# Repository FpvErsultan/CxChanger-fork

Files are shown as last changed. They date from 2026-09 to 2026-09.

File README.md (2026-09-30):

## 🧑‍🔧 玩家社区 / Community

**上传模型和图片、分享作品、参与投票，无需会 Git：** [直接进入玩家作品社区（上传模型） →](https://ers-ye.github.io/cxchanger/community/) · [在 GitHub 讨论区交流](https://github.com/ers-ye/cxchanger/discussions)

---

## 最新项目 / Project Update

- [后置换热端项目（中文）](./后置换热端/README.md) | [English](./后置换热端/README_EN.md)
- [6.11 CNC 文件包](./6.11%20cnc.zip)

# [CxChanger]

[CxChanger]是一种FDM3D打印多材料/多色解决方案。通过在打印打印过程中切换预热好的装载不同耗材的热端实现快速多材料打印。其目标是实现尽可能低成本且简单稳定的多材料打印，为了实现较高的适配性，热端切换只需要打印头XY轴运动就可实现，且切换结构与热端无关，可以通过修改热端固定件等实现其他热端的兼容。

English language readme is available [here](./EN-translation/README-EN.md)

打印头

QQ20260404-193802

---

## 核心特性
- **自动预热**：开启orcaslicer中的Ooze预防功能，会根据自己设定的预热时间提前在切换材料前插入预热命令，切换时释放旧热端并切换到待机温度然后抓取已经预热好的热端，若下一次切换的时间短于加热时间则保持温度不降温。
- **欠驱动切换机构**：采用欠驱动设计不需要额外增加主动元件，利用打印头自身的XY轴运动与停靠坞机械交互来实现热端切换和耗材丝夹紧松开。
- **磁吸麦克斯韦定位耦合机构**：热端模块锁定采用N52磁铁磁吸配合[麦克斯韦耦合](https://en.wikipedia.org/wiki/Kinematic_coupling)定位机构，打印头端有定位销组成的三个槽口，热端模块端有圆头销头部组成的球头。磁吸配合时实现对热端模块空间六自由度的限位，不存在过定位所以即使有加工装配误差以及磨损变形热端模块都能自适应消隙精确定位。
- **自动喷嘴偏移量校准**:采用校准器校准每个头XYZ轴相对T0的偏移量，可以使用如[小球微动接触式喷嘴偏移量校准](https://github.com/Noisyfox/FoxChanger/tree/main/NozzleProbe)或者[无接触涡流喷嘴偏移量校准](https://oshwhub.com/cxg01/project_lbabffjk)，接触式需要清理干净喷嘴才能获得正确喷嘴偏移量，无接触可以不清理喷嘴。不需要每次打印前都校准，通常在刚装配好或者出现撞头等情况需要校准。

## 硬件与软件需求

### 硬件
* **打印机** 原理上支持打印头具有XY移动能力的机型（如voron2.4、voron三叉戟、大鱼TT等），本开源只提供打印头和基础停靠坞设计需要根据自己机型固定装载停靠坞的铝型材和其他兼容修改。
* **主板** 由于采用有线加热，每个热端模块具有一个加热片和热敏，可利用主板空余接口来扩展少量热端模块，若需要扩展更多热端模块需要制作[扩展板]( https://oshwhub.com/rayzark/project_qxihkkhj)来增加主板的加热棒接口和热敏接口。

### 软件
* **固件** 整体热端切换通过klipper宏命令实现，若需使用喷嘴偏移量校准则需要下载[toolchange](https://github.com/viesturz/klipper-toolchanger)插件，配合自动校准宏来实现。
* **切片软件**：采用Orcaslicer，其他切片软件可自行探索。

## 组成概览

### 组成部分
- 打印头：有除了热端以外的其他部分
- 热端模块：包含热端，接有铁氟龙管和加热片和热敏的线
- 停靠坞：用于存放停靠的热端，可以堵住停靠热端的嘴防止漏料，以及有散热风扇给停靠的热端进行散热（无封箱的采用侧面离心风扇对所有热端进行散热、有封箱的采用每个停靠坞一个轴流风扇）。

### 零件
#### 打印版
- 1.5×5（直径*长）圆柱销：用于构成麦克斯韦耦合定位的槽（×6）
- 3×6（直径*长）圆头销：用于构成麦克斯韦耦合定位的球（一个热端3个）
- 5×20（直径*长）内螺纹圆头销：装配于停靠坞上用于撑开挤出机摆臂（一个停靠坞1个）
- 6×4（直径*厚）N52磁铁：用于吸附热端模块到打印头上和停靠坞上（一个热端3个，一个停靠坞1个，打印头3个）
- M3×6沉头螺丝
- M3×25螺丝
- M3×8螺丝
- M3×10螺丝
- M3×12螺丝
- M3×14螺丝
- M3×20螺丝
- M2.5×16螺丝
- M2×8螺丝
- M3×4×4热熔螺母
- HGX挤出机齿轮组
- 4020蜗轮风扇
- 2510轴流风扇
- 欧姆龙微动开关
- 10×2（宽×厚）自粘耐热硅胶条
#### CNC版
见bom表

## 安装与配置指南

### printer.cfg
   Printer.cfg主体可以沿用自己以前的，参考我的printer.cfg里的格式和下面的提示修改，也可以直接用我的然后改成自己主板的引脚。
   1. 引用 toolchange.cfg 和 calibration.cfg。
   2. 仿照extruder1格式定义增加的热端，加热棒热敏引脚按自己主板接线来，共用E0的挤出机，其他的为虚拟挤出机。
   3. probe采用固定微动，开始打印时热端全部停放于停靠坞中用耐高温硅胶垫堵嘴，加热到目标温度才拿出来解决初始漏料问题，不需要擦嘴，调平时未抓取热端此时微动为打印头最低点。还未支持其他调平方式，建议直接参考我的probe相关配置包括网床和调平的配置（主要是增加了调平前释放抓取的热端）。
   4. 添加停靠坞散热风扇配置，停靠坞散热风扇和喉管冷却风扇关联的挤出机里添加所有挤出机。
   5. 修改打印开始gcode，实现打印前自动给要使用的热端进行挤出划线。
   6. 修改打印结束gcode，添加UNTOOL命令保证打印完自动卸载热端，让下次打印时不用自己手动取下热端。增加关闭所有热端加热命令。
### toolchange.cfg
   1. 添加toolchange.cfg。添加成功后仪表盘界面会出现T0、T1、T2以及、UNTOOL命令，（没调坐标先别点、会直接撞）点击T0是抓去T0，抓取T0后再点击T1坐标会自动卸载T0然后抓取T1，点击UNTOOL是卸载当前热端。
   2. 固定停靠坞以及调整停靠坞坐标：手动把热端装到打印头上，把打印头拖动到X轴最右边，再往前拖动，然后把第一个停靠坞固定在能刚好让热端锁定螺丝穿过停靠坞大孔的位置（这个位置即为第一个停靠坞的坐标），然后取下热端，点击全部归位，再把热端装到打印头上，慢慢移动打印头到刚才找到的停靠坞位置让锁定螺丝穿过停靠坞大孔，记下此时的坐标将其填入toolchange里T0的停靠坞位置，一个停靠坞占30mm宽度，其他停靠坞坐标用等差数列得到，如有误差可自己微调每一个停靠坞的坐标。 
   

   3. 正确设置坐标后，注释正常速度，解除测试速度注释，用慢速进行切换测试，（方便看到没对齐直接点急停）。
   4. 测试速度切换正常后，注释测试速度，解除正常速度注释（可以根据自己机器情况自己测试出更为合适的速度）。
### calibration.cfg
   1. 下载[toolchange](https://github.com/viesturz/klipper-toolchanger)插件
   1. 添加calibration.cfg
   2. 归位xyz，调平完成后，固定好校准器，点击T0抓去第一个热端，移动至喷嘴尖端刚好位于校准器中心正上方距离1mm左右，记下这个时候的坐标，填入calibration.cfg里校准器坐标处，然后还需要在里面自己定义一个停靠坞范围外的安全位置，防止校准的时候撞到停靠坞里的其他热端。
   3. 坐标设置好后输入 CALIBRATE_TOOL TOOL=_ 可以校准指定热端（需要先校准T0），输入 CALIBRATE_ALL_TOOLS 可以校准全部（需要设定好有哪些热端），校准完成会自动存储偏移量。
### orcaslicer
   1. 修改打印机gcode里起始和耗材丝更换gcode、设置更多挤出机(根据自己热端数填写)、设置各挤出机切换耗材时回抽量（我设置的长度2mm）。
- 打印起始Gcode(根据自己的热端数修改)：
```Gcode
PRINT_START BED=[first_layer_bed_temperature] INITIAL_TOOL=[initial_tool] T0_TEMP={nozzle_temperature_initial_layer[0]} T0_USED={is_extruder_used[0]} T1_TEMP={nozzle_temperature_initial_layer[1]} T1_USED={is_extruder_used[1]} T2_TEMP={nozzle_temperature_initial_layer[2]} T2_USED={is_extruder_used[2]} T3_TEMP={nozzle_temperature_initial_layer[3]} T3_USED={is_extruder_used[3]} T4_TEMP={nozzle_temperature_initial_layer[4]} T4_USED={is_extruder_used[4]}
```
- 耗材更换Gcode：
```Gcode
M104 S{nozzle_temperature[next_extruder]} T{next_extruder}
T{next_extruder}
```
   2. 工艺栏里开启擦拭塔（如果料和参数调得好，且模型不涉及快速微小挤出，可以把模型拖到停靠坞旁边关掉擦料塔尝试无擦料塔打印）和Ooze自动预热（我设置的软化温度负180，预热时间35s，根据自己热端加热速度修改）。

## 注意事项
- 打印件采用abs打印，4层墙，60%填充。
- 挤出机弹簧需要拧得比常规挤出机更紧（因为为了压缩空间，力臂长度有限相同预紧力下挤出机夹紧力不如正常挤出机）。
- 为了减少热量传导效率，用到的TZ2.0热端需要去掉固定加热块的两个螺丝，仅靠侧面顶丝固定。
- 磁铁安装严格按图来（有的是压到底，有的是与某一面共面），装配正确应该是只有热端组件端的圆头销与背板端的圆柱销槽接触，磁铁之间有一点间隙，才能实现麦克斯韦耦合定位的自动消隙功能，可以自己晃动热端感觉有没有虚位，有虚位需要检查安装是否正确。当出现打印着精度变差的情况，需检查定位装配，容易出现磁铁没粘牢滑出与另一端的磁铁接触造成麦克斯韦耦合失效。
- 热端组件上用来挂在停靠坞孔里的挂钩螺丝用12.9级的杯头螺丝方便磁吸到停靠坞内，304材质螺丝无法正常吸附。

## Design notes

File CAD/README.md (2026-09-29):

# 6.11 Printhead CAD

Download the 6.11 printhead source model: [打印头6.11修正.STEP](https://github.com/FpvErsultan/CxChanger-fork/releases/download/6.11-cad/6.11.STEP).

The source STEP model is provided as a Release attachment because it exceeds the regular repository web-upload size limit.

## 中文说明

下载 6.11 打印头 STEP 源文件：[打印头6.11修正.STEP](https://github.com/FpvErsultan/CxChanger-fork/releases/download/6.11-cad/6.11.STEP)。

由于文件较大，STEP 源文件保存在本仓库的 Release 附件中。

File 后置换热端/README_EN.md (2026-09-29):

# Rear-Mounted Hotend Project

This folder contains the mesh model and motion parameters for a rear-mounted hotend/dock project. Before installation or motion, verify the model revision, mounting orientation, machine coordinate system, and available travel.

## Files

- `后置换热端完整全套 修复版本.stl`: the complete repaired STL mesh supplied for this project. STL does not contain a parametric feature tree and cannot be edited like a STEP solid; use suitable mesh or CAD software if geometry changes are needed.
- `dock_motion_parameters.txt`: the original Chinese dock-motion parameter snippet. The parameters are explained below.

## Dock motion parameters

```ini
variable_dock_shift_x: 3
variable_dock_dodge_y: -14
variable_dock_safe_y: -30
```

- `variable_dock_shift_x`: X-axis shift used to open or close the extruder arm.
- `variable_dock_dodge_y`: relative Y-axis clearance move.
- `variable_dock_safe_y`: relative Y-axis move for safely withdrawing from the dock.

The values are preserved from the supplied configuration. The source does not identify the coordinate reference, macro names, or compatible printer models. Check the actual Klipper macros for direction, units, and move order; do not assume every printer uses the same coordinate system.

## Klipper integration and commissioning

1. Back up the current configuration and find the dock/tool-change macro that reads these variables.
2. Put the values in the variable-definition section used by that macro. This is only a parameter snippet, not a complete `printer.cfg` or standalone macro file.
3. Check axis directions, travel limits, dock position, and clearance from the frame, toolhead, wiring, and other hotends.
4. Run the macro outside a print at low speed, ready to stop motion. Verify each direction and clearance move step by step before a full docking cycle.
5. After changing values, reload the Klipper configuration using your normal procedure and re-check every tool-change path.

If motion collides, binds, or differs from the expected path, stop immediately. Re-check the coordinate system, variable references, and clearance before proceeding. Do not try to solve an unknown path problem by simply increasing travel distances.

## Model and printing

Before use, check the STL units, scale, mesh integrity, and mounting orientation, then verify compatibility with the target printer. This folder does not specify dimensional tolerances, print material, slicer settings, or a complete macro, so validate those details for the actual hardware and machine configuration.

## 中文

参见 [README.md](README.md) 查看中文版。

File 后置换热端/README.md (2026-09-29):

# 后置换热端项目

本目录收录后置换热端/停靠坞项目的网格模型与运动参数。安装或执行运动前，请先核对模型版本、安装方向、机器坐标系及可用行程。

## 文件

- [完整修复版 STL 模型](后置换热端完整全套%20修复版本.stl)：STL 网格模型不含参数化特征树，不能像 STEP 一样直接编辑尺寸。
- [停靠坞运动参数](dock_motion_parameters.txt)：原始 Klipper 参数片段。
- [English guide](README_EN.md)：英文版说明。

## 参数说明

| 参数 | 值 | 作用 |
|---|---:|---|
| variable_dock_shift_x | 3 | X 方向横移，用于打开或闭合挤出机夹臂。 |
| variable_dock_dodge_y | -14 | Y 方向相对避让位移。 |
| variable_dock_safe_y | -30 | Y 方向安全拔出停靠坞的相对位移。 |

数值沿用提供的原始配置。原文未注明坐标基准、关联宏名称或适用机型；请结合实际 Klipper 宏核对方向、单位和运动顺序。此参数片段不是可单独加载的完整 printer.cfg 或宏文件。

## 集成与安全调试

1. 备份现有配置，找到实际读取这些变量的停靠/换头宏，再把参数放入该宏对应的变量定义处。
2. 检查坐标方向、行程边界、停靠位置与周围净空，确认不会撞到机架、打印头、线束或其他热端。
3. 在打印之外低速逐步验证方向和避让顺序，手边准备好停止运动；确认路径无碰撞后，再进行完整停靠测试。
4. 调整后按 Klipper 的正常流程重新加载配置，并复核所有换头路径。

若发生碰撞、卡滞或运动方向不符，立即停止并检查坐标系、变量引用和路径净空。不要仅通过增大位移来掩盖原因。

## 模型使用

使用前检查 STL 的单位、比例、网格完整性和安装方向，并结合目标打印机确认兼容性。当前资料没有给出尺寸公差、打印材料、切片参数或完整宏，这些内容需要根据实际结构单独验证。

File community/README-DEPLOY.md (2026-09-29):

# CxChanger 社区上传页部署说明

上传页接受原始 .stl、.step、.stp 文件，图片可选。GitHub Pages 负责页面；Cloudflare R2 保存文件，Workers 提供上传和审核接口，D1 保存作品、审核状态和投票。新投稿默认待审核，通过后才公开展示和下载。

## 部署前先了解

- 页面会公开展示审核通过的作品和图片；访客可以直接下载原始模型。上传者必须拥有公开分享这些文件的权利。
- Cloudflare 服务按计划提供月度额度，超出额度可能计费。请查看最新的 [R2 价格](https://developers.cloudflare.com/r2/pricing/) 和 [D1 价格](https://developers.cloudflare.com/d1/platform/pricing/)，并启用账单提醒。
- 单个模型限制为 25 MB，图片限制为 5 MB。接受 STL、STEP、STP、JPG、PNG 和 WebP。
- 投稿需完成 Turnstile 反垃圾验证。管理员密钥和 Turnstile Secret 只能保存在 Cloudflare Worker Secrets，不能提交到 GitHub。
- 收藏保存在访客自己的浏览器。投票按浏览器生成的 ID 对每个作品计一次；清除本地数据后可以再次投票，因此人气排序适合社区参考，不用于防作弊竞赛。

## 1. 创建 Cloudflare 资源

先在安装了 Node.js 的电脑上打开终端，并进入仓库中的 community 文件夹。以下命令由 Wrangler 创建 Cloudflare R2 和 D1 资源：

    npx wrangler login
    npx wrangler r2 bucket create cxchanger-community-files
    npx wrangler d1 create cxchanger-community

D1 命令会显示 database_id。把它填入本目录的 wrangler.toml，替换 REPLACE_WITH_D1_DATABASE_ID。ALLOWED_ORIGIN 与 TURNSTILE_HOSTNAME 保持为 https://ers-ye.github.io。

在 Cloudflare Turnstile 控制台为主机名 ers-ye.github.io 创建 Managed 小组件。记下 Site Key 和 Secret Key。Site Key 会公开写入页面配置；Secret Key 只设置为 Worker Secret。

## 2. 初始化数据库并部署 Worker

仍在 community 文件夹运行：

    npx wrangler d1 execute cxchanger-community --remote --file=./schema.sql
    npx wrangler secret put TURNSTILE_SECRET
    npx wrangler secret put ADMIN_TOKEN
    npx wrangler deploy

Wrangler 会交互式读取 TURNSTILE_SECRET 和 ADMIN_TOKEN。不要把这两个值写入代码文件或聊天。管理员密钥应使用随机生成的长字符串，并安全保存。

部署成功后，Wrangler 会显示 Worker URL，例如 https://cxchanger-community-api.<你的账户子域>.workers.dev。复制该地址并在末尾加上 /api。

## 3. 配置上传页并发布 GitHub Pages

编辑 config.js 中的 apiBase 和 turnstileSiteKey：

    apiBase: "https://cxchanger-community-api.<你的账户子域>.workers.dev/api",
    turnstileSiteKey: "粘贴 Cloudflare 提供的 Site Key",

这两个字段是公开配置，可以提交到 GitHub。不要把 Secret Key 或 ADMIN_TOKEN 写入 config.js。

完成后在仓库进入 Settings → Pages，把发布源设为 Deploy from a branch，选择 main 和 /(root) 并保存。页面地址为：

    https://ers-ye.github.io/CxChanger-fork/community/

根目录 README 的社区入口应链接到该地址。Worker 每天会清理创建超过 24 小时但未完成的临时上传记录及文件。

## 4. 审核作品

管理员打开以下地址，输入 ADMIN_TOKEN 后即可查看待审核列表：

    https://ers-ye.github.io/CxChanger-fork/community/admin.html

审核页可以预览图片、下载原始模型、通过并公开作品，或拒绝投稿并删除其模型和图片。管理密钥只保存在当前页面内存中；关闭或刷新页面后需要重新输入。

## 文件说明

- community/：公开社区页、作品广场、收藏和投票界面。
- community/admin.html 和 admin.js：管理员审核界面。
- community/worker.js：Cloudflare Worker API。
- community/schema.sql：D1 数据表结构。
- community/wrangler.toml：Worker、R2、D1 和每日清理配置。

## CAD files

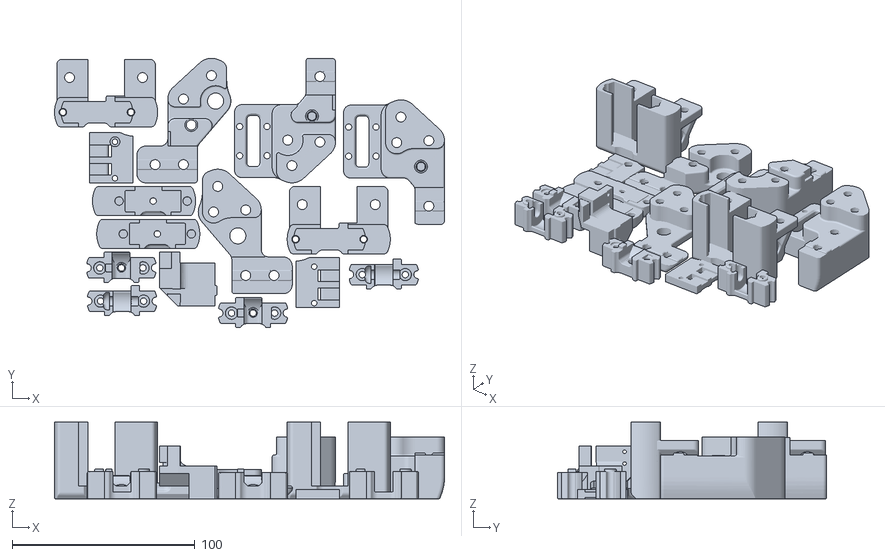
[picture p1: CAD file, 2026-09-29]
后置换热端/后置换热端完整全套 修复版本.stl
213.7 x 147.6 x 42.0

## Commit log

2026-09-29 添加 6.11 CNC 版本压缩包
    将 6.11 cnc.zip 放入仓库根目录。
2026-09-29 添加后置换热端中英项目说明
    This README provides details about the 后置换热端 project, including grid models, motion parameters, and integration guidelines.
2026-09-29 添加后置换热端模型与英文说明
    [dock_motion_parameters.txt, 后置换热端完整全套 修复版本.stl]
2026-09-29 添加项目导航并整理 README 入口
    Added project update section with links to recent projects.
2026-09-29 Create README.md for 6.11 Printhead CAD
    Added README for 6.11 Printhead CAD with download links.
2026-09-29 Replace old 6.11 CAD ZIP with original STEP release asset
